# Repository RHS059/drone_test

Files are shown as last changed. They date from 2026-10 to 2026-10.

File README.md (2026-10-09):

# Six-Wheel Builder

[Open the viewer](https://rhs059.github.io/drone_test/).

Source-backed six-wheel engineering viewer with original retained drive/suspension/steering interfaces, body panels and battery/electrical components, plus licensed UR20/Robotiq mechanisms and a separate live MuJoCo gripper experiment.

See [the current assembly record](docs/RECONSTRUCTION.md) and [original source downloads](docs/assets/connected-sources/index.html). Independent front/rear steering, wheel spin and optional unloaded suspension study are executable. Purchased profiles, wheel-seat approval, load/fatigue ratings, complete wiring, UR controller mounting and vehicle operation remain open. The old workshop cradle is disabled because it intersects this revision.

The supported main isolator-to-BMS cable pair has its own [source and limits](docs/assets/main-pair-E05/index.html). Full electrical continuity remains unfinished.

Run `node test-main-pair.mjs`, `node test-real-gltf-body.mjs`, `node test-connected-mechanics.mjs`, `node test-current-rover.mjs`, `node test-composed-body.mjs`, `node test-electrical-scene.mjs`, `node test-rigid-matrix.mjs`, `node test-controls-ready.mjs`, `node test-costs.mjs`, `node test-cad.mjs`, and `node docs/contact/scripts/validate.mjs`. Historical C03 tests and assets are retained as history, not current assembly qualification.

The exact public files are listed in the release manifest. Restricted manufacturer CAD, private credentials and review-only geometry are excluded. Source-specific licenses and original modeling assumptions remain with each package.

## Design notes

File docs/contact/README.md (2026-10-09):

# Standalone reconstructed gripper contact laboratory

This is a **new reconstruction**, not recovered historical test parameters or a claim that the original package survived. It does not validate a complete six-wheel robot, manipulator, compliant object, hardware, or a contact-calibrated digital twin.

## Reproduce

Serve this folder with an ordinary static HTTP server and open `index.html`. All browser imports are relative and vendored. It runs actual official MuJoCo WebAssembly locally in the browser; recorded CSV/JSON is not used to animate it.

Native: install official `mujoco==3.15.0` into your environment, then run `python scripts/run_native.py`. In the reconstruction workspace the invocation was `PYTHONPATH=/tmp/ugv-mjpy python scripts/run_native.py`.

WASM and parity: `node scripts/run_wasm.mjs && node scripts/validate.mjs`. Both runtimes report 3.15.0. `scripts/browser_qa.py` uses Playwright and Chromium against localhost port8788. `scripts/build_scenarios.py` regenerates the original coupon STEP/STL (requires CadQuery) and experiment XML. `scripts/fetch_sources.py` captures official pinned Menagerie files; see `sources.json` for immutable URLs and SHA256 checksums.

## Model and exact units

- Google DeepMind MuJoCo Menagerie Robotiq2F85, commit `0059d4335f8156206f63a35662313385f7ad6d74`. Source XML and eight STL geometry files are retained unchanged, together with BSD-2-Clause license, README and changelog.
- Menagerie meshes are millimetres; the upstream mesh scale remains `0.001 0.001 0.001`. Joint positions, inertias, masses, tendon, two closed four-bar connect constraints and driver equality remain sourced from that model.
- Coupon is an original analytic rectangular solid,40×40×30mm, centered at CAD origin. STEP and STL are in **millimetres**. It is freshly generated, not a recovered historical binary. MJCF collision is the exact equivalent box with half sizes `0.02 0.02 0.015` **metres**; no mesh simplification changes its shape.
- Simulation SI units: metres, kilograms, seconds, Newtons. Mass is independently assigned, not inferred from the coupon CAD material. Nominal and low-friction0.15kg; heavy2kg. These masses correspond to artificial test loads rather than a claimed material density.
- Upstream gripper pad collision proxies remain the original boxes. Link mesh collisions use MuJoCo convex collision geometry, as standard in Menagerie. This is not a soft silicone or deformable-contact model.

## Declared scenario

`scenario.json` is the authoritative parameter declaration. Gravity9.81m/s², timestep1ms, implicitfast integration,100 solver iterations, tolerance1e-10, elliptic friction cone. Duration5.5s;550samples at10ms intervals per case. Gripper mounted downward atz0.3m; coupon center initiallyz0.1512m. Source position actuator command ramps0→200 at0.2–1.2s, force limits remain upstream±5.

The only coupon weld is explicitly `initial_world_fixture`, coupon-to-world, active until1.5s. It is disabled permanently before transport. **There is no object-to-gripper weld or kinematic object following.** The gripper base follows a prescribed100mm horizontal smoothstep at2–3.5s. Gripper opens at4s. Coupon position, contact, normal forces, falling and slip are solved from dynamics.

Nominal friction0.7; low-friction0.015; heavy friction0.7. Coupon geom priority2 makes these sliding coefficients effective for contacts against upstream priority1 pads. Torsional and rolling friction are0.005 and0.0001. Strict task PASS means maximum Euclidean coupon-to-prescribed-center error is **less than10mm** over1.6≤t<4s. Heavy is a changed load, not necessarily a failing negative control.

## Fresh measured results

Native / WASM strict task results agree:

- Nominal: worst transport error2.61103mm, **PASS**.
- Low friction:152.31481mm, **FAIL**, real slip/drop before opening command.
- Heavy:2.37696mm, **PASS**.

Nominal/heavy commanded release is observed: coupon remains above0.1m immediately before4s and falls below0.05m by5.5s. Low-friction already dropped and is deliberately **not** counted as successful commanded release. The software regression harness can pass while the low-friction experiment fails.

Maximum sampled native/WASM coordinate difference is1.2915µm and contact-normal-force difference0.03704N. The initial1µm numerical gate **failed**. A documented10µm gate is used for nonsmooth-contact numerical agreement (1000× tighter than the10mm task gate); the original failure is preserved in `summary.json`. This is bounded numerical agreement, never exact bitwise parity or real-world validation.

Pad force is the sum of scalar normal forces only for coupon–pad contacts. Total contact normal force additionally includes the floor; a heavy coupon's floor impact peak must not be presented as gripper force. Raw sampled position, qpos, fixture status, command and forces are retained in native/WASM JSON.

## Browser QA status

Live Node execution of the same WASM module passed. Browser launch in this executor is blocked: Chromium cannot create its process-singleton socket (Operation not permitted), including an escalated retry. Browser screenshots, visual layout, pause/reset and actual browser loading therefore remain unverified until a permitted browser environment runs `scripts/browser_qa.py`. This is recorded separately in `results/browser-qa.json`.

## Browser module API

`createEngine(readBytes?)` loads official single-threaded WASM. Default asset loader uses relative fetch. `engine.createCase('nominal'|'low-friction'|'heavy')` returns `{model,data,mj,step(),sample(),dispose(),stepCount}`. Call5500steps and sample every10steps. `summarize(samples)` calculates declared metrics. `validateParameters()` rejects invalid nonfinite/nonpositive masses and negative/nonfinite friction; the shipped UI deliberately exposes only the three fixed declared cases.

## Attribution

Menagerie Robotiq model:BSD-2-Clause, retained `assets/robotiq_2f85/LICENSE`. Official MuJoCo3.15.0 JavaScript/WASM:Apache-2.0, retained `vendor/LICENSE-MUJOCO`, package README and metadata. Three.js renderer:MIT, retained `vendor/THREE-LICENSE.txt`. Original scenario, scripts, UI and coupon are new work for this reconstruction. No private soldier assets or external CAD are involved.

Validation is read-only by default. To intentionally regenerate the summary after new native/WASM runs: `node scripts/validate.mjs --write`.

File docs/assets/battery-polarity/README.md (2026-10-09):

# BA02 polarity correction R01

This separate correction establishes the functional polarity of the four existing BA02 terminal interfaces. It changes viewer labels and semantic terminal colors only. It does not modify the frozen BA02 CAD, source generator, geometry, transforms, source node names, or original source/evidence ZIP. No vendor PDF, image, mesh, logo or manufacturer geometry is included.

## Result

In the installed BA02 frame, positive is **Y +275.25 mm** and negative is **Y −275.25 mm** on both batteries. The original node names assigned these polarities backwards.

| Frozen source alias, retained unchanged | Verified functional polarity | Terminal-axis top in CAD C, mm | Viewer color |
|---|---|---|---|
| `BA02_pack_1_negative_M8_interface` | Positive (+) | (−1029.05, +275.25, 169.6) | Red `#e53935` |
| `BA02_pack_1_positive_M8_interface` | Negative (−) | (−1029.05, −275.25, 169.6) | Dark `#20252b` |
| `BA02_pack_2_negative_M8_interface` | Positive (+) | (−679.05, +275.25, 169.6) | Red `#e53935` |
| `BA02_pack_2_positive_M8_interface` | Negative (−) | (−679.05, −275.25, 169.6) | Dark `#20252b` |

These colors are a deliberate viewer convention, not source evidence about physical terminal coating or insulation color. The frozen source used a shared bronze terminal material for both polarities and the top fittings.

## Exact source and orientation proof

The official Victron Energy BAT548110620 drawing is [LiFePO4 Battery 51.2 V / 100 Ah NG, Dimension Drawing](https://www.victronenergy.com/upload/documents/LiFePO4-Battery-51.2V100Ah-NG.pdf), page 1, top plan view. Its rendered polarity marks were visually inspected on 2026-10-09: positive on drawing-left and negative on drawing-right.

Exact inspected PDF SHA-256:

`d153636d0bb1cb84ea4c3c339746618c97fd02859398404febbc8a92a2a27d4b`

1. The drawing's overall width is 647.6 mm. Its asymmetric top fitting is 376.3 mm from the left edge, hence 376.3 − 647.6 / 2 = **+52.5 mm toward drawing-right**.
2. The frozen BA02 fitting center is **Y −52.5 mm** on both packs. Therefore drawing-right maps to **CAD −Y**. The asymmetric fitting, not terminal names or existing wires, resolves the orientation.
3. Positive is on drawing-left, so it maps to **Y +275.25 mm**. Negative is on drawing-right, so it maps to **Y −275.25 mm**. The absolute axis offset is the frozen symmetric terminal pitch, 550.5 / 2 = 275.25 mm.
4. The terminal depth-edge offset establishes X = pack center − (161.5 / 2 − 26.7) = pack center −54.05 mm. Pack centers are X −975 and −625 mm.
5. Z 169.6 mm is the preserved BA02 terminal-reservation top. It is not a newly qualified hardware height. The existing source-height discrepancy remains unresolved.

The drawing's rounded 48.5 mm end offset differs by 0.05 mm from its symmetric pitch-derived location. This metadata-only correction preserves the frozen axis placement. The source/mesh regression uses a 0.01 mm tolerance only for tessellated-circle extrema and float32 mesh positions; exact manifest and contract dimensions use 1e-7 mm tolerance.

The frozen generator's note that installed polarity is an orientation choice is superseded by this correction. Its legacy names remain trace aliases only. Do not use those words to infer electrical polarity.

## Runtime integration

Copy `apply-battery-polarity.mjs` and `battery-polarity-contract.json` together with the viewer's original runtime assets. After all named body patches have composed BA02 and the normal asset loader has assigned its labels, call:

```js
import { applyBatteryPolarity } from './apply-battery-polarity.mjs';
const polarityContract = await fetch('./battery-polarity-contract.json').then(r => {
  if (!r.ok) throw new Error('Battery polarity contract unavailable');
  return r.json();
});
const polarityResult = applyBatteryPolarity(body, polarityContract);
```

`body` is the composed source-frame Object3D, not a newly generated or moved battery. The helper is import-free and supports Three.js Object3D and Material APIs already used by the viewer. It:

- Validates the exact drawing hash, source dimensions, marked sides, asymmetric-fitting sign, all four functional mappings, labels, colors and open qualification gates.
- Resolves all four legacy aliases uniquely before staging changes. Missing or duplicate source nodes throw without modifying the scene.
- Stages all material clones and metadata before applying them. A late clone failure leaves the scene unchanged. Each cloned material must have its own color object.
- Retains each `node.name` exactly, and stores its source alias and verified functional identity under `userData.batteryPolarity`.
- Sets `userData.label` and `userData.displayLabel` on each terminal source node and every descendant mesh, so the viewer's mesh-selection label reports the functional polarity.
- Gives every corrected mesh an independent cloned material; array materials are supported. It does not recolor shared original metal, either top fitting, or unrelated hardware.
- Never writes geometry, node names, hierarchy, position/quaternion/scale, visibility, local/world matrices or update flags.

The proposed functional identity is `BA02_pack_{1,2}_{positive,negative}_M8_interface_VERIFIED_R01`. This is metadata only, not a silent runtime `node.name` rename. A circuit or endpoint graph must retain the exact source alias for geometry resolution and use the verified functional polarity/name for its electrical semantics. Existing cable paths do not establish polarity or authorize their own connections. The electrical owner must separately reconcile any affected edge labels and endpoints.

Suggested viewer download notice:

> Frozen BA02 CAD keeps its original source node names, which invert the terminal polarity wording. The viewer applies the separate BA02 polarity correction R01: positive Y +275.25 mm and negative Y −275.25 mm. Consult the correction map before using terminal names. Wiring and terminal/lug qualification remain open.

Link that notice directly to this correction package when publishing the immutable BA02 download.

## Regressions and preserved inputs

`battery-polarity-contract.json` records the source facts, derivation, source-to-functional map, labels/colors, gates and SHA-256 hashes of all 17 frozen inputs, including the BA02 generator, all frozen BA02 artifacts and original archive.

Run the independent, read-only source/mesh regression from any directory:

```sh
python verify-source-polarity.py --ba02-root /path/to/battery-alternative --source-pdf /private/path/to/official-drawing.pdf
```

The PDF argument is optional for a redistributable text-only package. When supplied, its exact bytes are hash-verified without copying it. Without it, the report explicitly says `not_supplied`; the script does not claim a fresh PDF verification. The script checks actual GLB vertices, the asymmetric fitting, four terminal positions, functional polarity, semantic colors and preservation of all frozen hashes. It does not machine-read the plus/minus artwork; that observation comes from visual inspection of the hashed source document.

Run the runtime regression in the original workspace layout:

```sh
node test-battery-polarity.mjs
```

For another workspace, point `THREE_MODULE`, `CAD_READER_MODULE`, and `BA02_GLB` to existing viewer dependencies and the frozen BA02 GLB. The reader must return Three.js Object3D meshes in unchanged source coordinates. No dependencies or vendor meshes are bundled here.

The recorded runtime result passes 14 tests against the actual frozen BA02 GLB: source/fitting derivation; measured terminal/fitting positions; all four labels/colors; preserved geometry/matrices; shared-material isolation including array materials; missing-node and duplicate-node atomic failure; late clone failure; shared-color clone rejection; reversed-source/coordinate/gate negative tests; and repeat application.

Files `source-regression-results.json` and `runtime-regression-results.json` are bounded test evidence, not certificates of a working electrical assembly.

## Qualification limits

Only polarity interpretation is source-verified. The following remain false or open:

- Terminal hardware, recess, lug, bolt and cable-contact qualification
- Full harness completion and physical electrical continuity
- Protection, BMS, fusing, isolation, controls and conductor selection
- The underlying source-height discrepancy or exact vendor hardware reconstruction
- Vehicle operational or electrical safety qualification

No cable continuity test is used as proof of polarity, no physical reconnection is performed, and no complete-wiring gate is closed by this patch.

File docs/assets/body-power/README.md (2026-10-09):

# Body/power R01: original engineering CAD

This package replaces an exposed ladder-only appearance with functional compartment geometry. It is a manufacturing-development assembly, not fabrication-released, electrically qualified, weatherproof, crash-rated or ready to operate.

## Coordinate and source contract

All original construction is parametric CadQuery B-rep in millimetres, frame C: X forward, Y left, Z up. GLB vertex positions are metres and Z-up; no root correction rotation is required. Mount origins remain the R06 frame origins. Geometry is not stretched to match photographs.

- `body_power_R01.step` / `.glb`: original sheet parts, rail straps, stiffeners, hatches, gaskets, hardware approximations and cable troughs. No purchased electronics are disguised as detailed CAD.
- `cots_reservations_R01.step` / `.glb`: six explicitly named DIMENSION_ONLY cuboids: four RELiON batteries and two UR OEM DC controllers. Load only as a separate optional translucent packaging layer.
- `build_body_power.py`: reproducible source. `python build_body_power.py` rebuilds and verifies. CadQuery 2.7 and NumPy are required.
- `verification.json`: current solid validity, actual bounds, geometric mass/CG assumptions and intersections. Frame, arms, wheels and drive masses are excluded.
- `original_cutlist.csv`: one row per original part. This is a finished-geometry list, not a released flat-pattern/nesting set.
- `sourced_bom.csv`, `SOURCES.json`: primary-source identity, dimensions, mass and limitations. No purchase or vendor approval is claimed.

## Mechanically useful features

The recessed battery well sits between the existing X −1200 and −400 crossmembers, inside the rails. Four upright 260×180×276 mm reservations rest on 4 mm isolator pads; the reserved bank weighs 62.4 kg. Its original aluminium floor/walls, low stops and top crossbar provisions are explicit solids. Terminal positions and a validated hold-down contact interface remain unknown; the bars have a 12 mm nominal clearance and must not be represented as a completed restraint design.

The rear bay has two distinct elevated controller mounting trays with actual adapter slots, free connector/air volume and removable top access. The middle bay is retained as tool/payload volume. The forward compartment uses a real planar sloping nose and removable hatch. No weapon, targeting system or weapon mounting interface is included.

The outer body has separate 3 mm panels, shaped transverse bulkheads, sloping shoulder plates, four side inspection panels, top hatch joints with gasket solids, M6 clearance holes/nutplate provisions, simplified socket-head screws, cable troughs and actual connector/vent apertures. The top remains segmented for access. Rails are attached using wrap-around strap-clamp provisions, with no undisclosed new holes in the inherited frame. Fastener threads, bolt preload, rivet-nut choice, weld details, bend allowance, insulation and bonding still need engineering release.

The broad upper-hull span is a design choice suggested by non-dimensional reference-image cues. Its underside respects the current provisional suspension reservation; that does not establish swept-envelope clearance. The lower body has explicit cutouts for the current station-centred wishbone clamp reservation, at X −1350, 0 and +1350 mm. Do not use the superseded trailing-arm relief positions.

## Service and access

The battery hatch removes vertically; all four battery envelopes can then lift vertically with restraints removed. The controller bay is top-accessible; full connector extraction and fan service remain to be validated against acquired supplier CAD. Side inspection panels are supplemental, not battery-extraction doors. Front and middle tool hatches are separate from arm mounting plates. The arm bases at X900, Y±300, Z130 mm retain their existing bolt patterns; arm-link clearances must be checked in the actual default and motion poses.

Finger slots and ventilation openings are intentionally open geometry. The concept gaskets do not confer IP protection: sealed handles, fans/filters, drains, glands, cable penetrations and full thermal/environmental qualification are outstanding. The design must not be sold or described as a sealed battery enclosure or a certified safety system.

## Power architecture limits

The four proposed batteries provide 6.144 kWh nominal arithmetic energy, not usable energy or range. Their individual ratings do not imply system current capability. The UR source lists OEM DC input 19–72 VDC, up to 400 A inrush and 350 W control-unit heat per UR20. Two controllers require verified precharge/soft-start, fuse coordination and thermal design; nominal voltage overlap is insufficient. Standard UR control boxes require AC and are not equivalent to these provisional OEM DC reservations.

At a hypothetical 15 K air rise, removing the 700 W combined controller heat bound would require roughly 0.039 m³/s ideal airflow using assumed air density 1.2 kg/m³ and heat capacity 1005 J/(kg K). This calculation excludes pressure losses, ambient extremes, drive losses, battery heat and fan derating. It is a sizing warning, not fan selection or a cooling-performance claim. Current small vent slots alone are not qualified to deliver this flow.

Traction motors/controllers, regeneration, contactors, fuse ratings, BMS coordination, charger, emergency stop architecture, functional safety and grounding are all unresolved. No WD220 proprietary/restricted CAD is part of this package. No electrical connections are portrayed as a qualified system.

## Verification meaning

Mass is computed from CAD volume using stated nominal densities. Battery/controller masses come from manufacturer data; their CGs are placed at envelope centres as assumptions. This does not validate full-vehicle CG, tip stability, axle loads, braking or manipulator reaction loads. Frame mass and structure remain a separate package and may be redesigned. Pairwise positive-volume checks are CAD interference checks, not strength, safety or manufacturability certification.

The original bumper tubes are open-ended hollow-section geometry with separate caps. They are unqualified guards, not towing/recovery points or impact-rated bumpers. No recovery rating is invented.

## Traction candidate and optional second bay

The WD220 drawing lists47A within the motor block, without explicitly defining DC-bus input current. Six such ratings sum282A arithmetically; that is not verified battery demand. Inverter current/efficiency data are needed. A separate power check is possible: if six drives simultaneously deliver2.2kW mechanical output each,13.2kW/51.2V requires257.8A even at ideal100% efficiency, before arms/auxiliaries. Actual input would be higher. This exceeds the four batteries'180A summed individual recommended discharge, but does not by itself exceed the400A sum of individual maxima; neither sum is a qualified pack rating. The motor duty is S2 for60minutes, not continuous. Drive price and exact mass are unquoted/unknown. No motor/controller/battery compatibility is claimed. Controller heat is used for cooling sizing only and is not added again as independent electrical input power.

A separately recessed optional four-unit bay is geometrically possible within the R06 opening between crossmembers X−400 and+750mm, provisionally at X[−300,+350],Y±360,Z[−80,+337]mm. It is not modeled or included in mass/capacity. The present tool-bay interior is234mm high and cannot hold276mm batteries above its unmodified floor. This variant requires a new lowered well, changed floor, qualified retention and loss of that tool/payload volume; electrical limits do not disappear by adding units. See reservation_checks.json.

## Portable / Colab execution

The package includes the original reference_frame_R06.step solely for body/frame interference checks. Run the included requirements installation in an authorized Python/Colab environment, then build_body_power.py. Main STEP/GLB generation does not depend on private assets or network downloads. The optional arm-screen scripts require the separately licensed original robot asset folder; set its path in check_arm_clearance.py before use. This package was executed in the current engineering environment; it does not claim execution in Colab.

## C02 suspension packaging update

Current provisional wheel centres are Y±0.94m and Z−0.25m, superseding Y±0.86m. The lower corner relief is480mm wide belowZ132mm. Local160mm-wide coilover service notches extend toZ215mm. C02 shock envelopes are Xstation±60mm, |Y|520–800mm and Z−430..200mm; no actual spring has been selected. The source-dimension tyre concept is876.3mm OD and317.5mm provisional section. The analytic parallel-link, locked-steering ±12° check gives about94mm minimum lateral body-to-tyre envelope separation; this is not actual tyre/rim fit, loaded clearance or certified travel. See tire_envelope_screen_C02.json and reservation_checks.json.

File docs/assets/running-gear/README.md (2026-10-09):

# Archived source reference

These BSD-licensed Clearpath Warthog models were acquired for comparison. They are not loaded by the current six-wheel vehicle scene and are not the selected wheel or drivetrain. The selected source-backed wheel model is in ../wheels/. Original four-wheel Warthog ratings do not qualify this six-wheel design.

# Genuine running-gear source assets

Retrieved 2026-10-09 from the official Clearpath Warthog ROS description distribution:
https://github.com/warthog-cpr/warthog/tree/kinetic-devel/warthog_description

## What this contains

- Original OEM-distributed STL simulation meshes: wheel, two-wheel rocker enclosure, fenders, differential link and suspension link.
- GLB conversions in metres, Z up. Wheel, rocker and fender GLBs rotate the source by Z+90 degrees, preserving every triangle and applying NO scale. Remaining links preserve source coordinates. See interface-contract.json.
- Source Xacro graph, package BSD declaration and repository BSD-3-Clause LICENSE.
- Per-file upstream Git blob IDs and URLs in source-manifest.json, actual downloaded SHA256 hashes, triangle counts and bounds in geometry-report.json.

These are CAD-derived source **meshes**, not STEP/B-rep solids or toleranced manufacturing drawings. Wheel geometry is 12,680 triangles. It is not watertight after exact vertex merging; no topology repair or invented hub was introduced.

## License evidence

The root BSD-3-Clause license and robot-description package.xml BSD license are included. The mesh directory listing contains no separate license/exclusion. This is the published distribution's license evidence, not an additional legal opinion or grant of patent/trademark/manufacturing rights. Retain LICENSE in source and redistributed GLB documentation; do not imply Clearpath endorses the new assembly.

## Fit and limitations

Wheel GLB origin is the OEM axle center; axle +Y; nominal tire 610 mm; actual rotating mesh envelope radius 304.931 mm; actual width 254.300 mm. The source's 15 kg mass and radius 300 mm are simulation parameters. Hub bolt circle, pilot, axial mounting plane, rim offset, tire pressure/load curve and radial/axial load limits are NOT verified. Wheel has simplified filled low-poly center faces, but no identifiable lug holes; it does not provide an independent hub or motor assembly. A ray along its axle intersects mesh at sourceX -0.08654228 and +0.001998188 m (GLB Y after rotation), not certified mounting planes. Do not label a newly designed spindle as OEM-compatible without the supplier drawing.

Source Warthog is four-wheel, 1.52 x 1.38 x .83 m. Its whole-vehicle 280 kg base and 272 kg payload do not qualify the sedan-size six-wheel design. Its unmodified rocker holds TWO wheels at 914.734 mm wheelbase and cannot be transplanted onto the six single-wheel stations. Rocker and link GLBs are reference-only unless used in a fully redesigned and verified layout. The source labels the diff-link purely visual and does not model a constrained suspension linkage or motor internals.

## Purchasable candidates, not CAD/fit matches

The OEM manual identifies a 610 mm Argo Turf tire but does not identify an exact stock wheel part. A dealer offers a current 24x10-8 Argo XT115 tire (10002C) at USD380.74 and standard steel mounted left/right assemblies (10002C-STD-LEFT/RIGHT) at USD498.45 each, observed2026-10-09:
https://www.argoadventure.com/10002C--24x10-8--ARGO-XT115--TIRE-ONLY_p_18093.html
https://www.argoadventure.com/Standard-8-Rim-and-Tire_c_3689.html
These are procurement leads only: XT115 is not verified as the source's Argo Turf tire, and no load/bolt/mounting equivalence is established. Price excludes shipping/tax.

A separate dealer identifies Argo125-13BL 8x7 steel rim as five-lug,4.5-inch pattern, but this is NOT proof that the Warthog mesh depicts that rim:
https://adair-argo-sales.myshopify.com/products/rim-8x7-5-bolt-black

Timken32008X official CAD/product lead (not downloaded; page returned410 through web fetch):
https://cad.timken.com/item/tapered-roller-bearings-ts-tapered-single-/tapered-roller-bearings-ts-tapered-single-metric/x32008xm-y32008xm

No suitably sized license-safe motor/geared-hub CAD was acquired. Do not replace this gap with invented internals or a toy motor design.

## Rebuild

Run convert_assets.py with numpy/trimesh available. Exact source mesh arrays are retained; per-vertex visual gray is assigned only for visibility. Validate wheel rotation/contact using interface-contract.json; glTF loader must honor the documented Z-up content, because glTF conventions otherwise commonly assume Y-up.

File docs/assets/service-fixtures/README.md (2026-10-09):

# S01 original static workshop fixtures

Engineering-development CAD, not fabrication released or safe to use. These original fixtures have no safe working load, proof test, material-grade approval, weld design or stability approval. They are not lifting equipment, commercially rated stands, an autonomous mechanism or manufacturer-approved accessories.

Current corner contract: C02_R05, retaining upright R04 and wheel adapter R02. Adapter R02 changes only pilot-hole size, so fixture placement is unchanged.

## What is actually modeled

- Two independent original transverse chassis trestles at X = −1775 and +1775 mm. Each has a plate-built hollow crossbeam, two vertical hollow posts, two floor plates and two rail-bearing saddles. The frame is not drilled, cut or welded.
- Four 160 × 220 × 16 mm saddle plates bear directly under the R07 200 × 100 × 6 main rails at Y = ±460, Z = −100 mm. Each spans the complete rail width. Actual contact is the rounded rail's 76 mm-wide bottom flat; local web/bottom-wall load transfer remains unqualified.
- Four screw-adjusted side locators per saddle provide an actual mount/registration mechanism. Gravity flows through the saddle into the trestle, not through locator friction. Locator screws must never be called lifting points or relied on to prevent uplift. The side bosses have smooth bores representing unresolved threaded manufacture; threads, screw locking, tip attachment, preload and rail wall crushing need design review.
- A separate floor-supported wheel-corner cradle uses two hollow contour-shoe weldments, replaceable nominal 6 mm elastomer liners, two longitudinal rails, two transverse rails and four feet. The shoes follow the selected tire's stated 438.15 mm unloaded radius. The tire model is original C01 reference geometry; fitted width, actual tread contact and compression are unknown.
- Four removable bolted capture-post weldments and two removable bolted crossbars form an enclosing cage around the tire. The posts must be removed during cradle insertion. The cage is not a rated restraint, lifting bail, tie-down or personnel guard. No hoist hooks, drive-housing contact geometry, wheels, casters or autonomous motion are invented.

STEP is millimetres. GLB is metres, Z-up, in rover C coordinates (X forward, Y left). The cradle is at the middle left wheel; apply a proper Rz(180°) rotation for the right side, then translate X to the desired station. Do not use negative scaling. Four-point chassis saddle centers form a 3550 × 920 mm rectangle. This does not demonstrate a stable vehicle in any arm pose.

## Deliberate service scene and height

The nominal C01 tire floor is Z = −688.15 mm. S01's illustrative floor is Z = −788.15 mm, representing a 100 mm raised chassis while the C02 links remain at q = 0. The chassis saddle underside is Z = −116 mm, therefore 672.15 mm above this floor. The trestles are purpose-dimensioned original CAD for that one pose; they do not telescope or lift. Each fixture must be positioned before receiving load. Other heights require engineering a different fixture; do not add loose packing.

ESCO 10498 is not assigned to this model. Its maximum 546 mm saddle height is below even the unraised saddle underside (572.15 mm), and its manual limits accessories/adapters to manufacturer-supplied ones and prohibits adding material for height. US Jack taller candidates do not automatically solve the configuration: their one-end matched-pair usage restriction must not be reinterpreted as approval for four stands under the full vehicle. No commercial load rating transfers to S01. At either end wheel station, the nearest cradle and trestle foot edges have only 5 mm nominal lateral separation. Placement tolerance, floor unevenness and loaded deflection must be checked; this is not a released workshop aisle or installation clearance.

The CAD-only assumed mass is about 97 kg per trestle and about 90 kg for the cradle (see the latest verification JSON for exact values). They are not hand-lift or UR20 payloads. A separate reviewed handling/positioning method is required before these fixtures can be deployed; none is claimed by this geometry.

## Load paths and remaining interfaces

Chassis: main rail bottom flat → saddle plate → transverse box → two vertical boxes → floor plates → qualified floor. Locator screw loads, local rail bending/crushing, column buckling, box torsion, eccentric loading, welds, base plate bending, foot contact, anchorage and overturning are unresolved.

Corner: tire tread → liner → curved shoe top/walls/base → transverse members → longitudinal members → floor plates → floor. The drive/upright hangs inboard from the wheel through existing joints, so the full module mass and CG must be measured and a tip/stability calculation performed. The original upright is deliberately not supported on guessed OEM drive housing surfaces. A future direct upright support should contact checked original non-bearing lands; S01 does not add one.

The CAD's two contact shoes and enclosing cage do not establish adequate module retention. Liner bonding/mechanical retention, tire condition/inflation, compressibility, proof loading, blocked-movement behavior, lateral capacity and floor anchorage remain gates. Ground contact is not automatically anchorage: foot holes are original unqualified patterns and no anchors are selected.

## Bounded C02 removal and inspection sequence

This is a proposed design sequence for review, not an executable approved workshop procedure. Do not proceed past a missing precondition.

1. Establish an approved vehicle isolation/lockout plan; isolate traction and arms, control brake release, chock the still-grounded wheels and identify stored energy. C02 connectors and the coilover are not selected, so those manufacturer procedures remain open.
2. Measure the entire vehicle and removable-module masses/CGs; calculate worst-case support reactions and all intermediate stability cases. Select and qualify actual lifting points, jack/hoist, sling/fixture, headroom and lift height. S01 supplies no lifting attachment; the current frame has no qualified lifting lugs. Initial raising is blocked until this is resolved.
3. With qualified equipment carrying the load under human supervision, position the two engineered trestles and the unloaded cradle at the selected corner. Remove the cradle's four capture-post weldments and two crossbars for insertion, leaving its floor frame/shoes assembled. The 100 mm raised q = 0 pose is illustrative; actual suspension droop and insertion clearance need checking. Seat all four chassis saddles and the corner support through a reviewed load-transfer process with load measurement. Do not assume equal stand reactions or four-way load sharing.
4. Install and inspect the cradle's four post weldments (eight base fasteners) and two crossbars (four upper fasteners). Establish independently qualified anti-tip/anti-rotation restraint for the actual corner, and check full module load/CG. Do not release a corner held solely by robot arms.
5. Positively support both wishbones in their retained chassis position and control all coilover/spring energy by the selected manufacturer's procedure. Those support devices are not in S01, and the planned C02 coilover is unselected: pin release remains blocked. The chassis rail clamps and their through-tie hardware remain installed.
6. After the preceding checks are released, isolate/disconnect the exact drive/brake/sensor connectors and remove the retention devices for the two outer X-axis upright pins. Final pin retention is not designed in C02. An original Ø28 mm extraction corridor from X −260 to +260 mm was screened against the S01 cradle ONLY. A subsequent exact containment test finds the installed modeled tire on that centerline at X offsets ±220 mm. The full corridor is obstructed; a verified wheel-first or alternative-access procedure and real extraction tool are required. See pin_axis_tire_obstruction.json. Withdraw the two outer pins only while the external workholding carries the corner and both links remain positively supported. Do not remove inner pivot or rail-clamp bolts.
7. The C02 service boundary is wheel + adapter + drive + upright. Wishbones, stationary rail clamps and planned coilover remain on the chassis. Keep the detached module supported in the stationary cradle for inspection. Moving it away, lifting it or rolling it requires a separately engineered transport/lifting attachment and sequence; S01 deliberately does not animate or assert that operation.
8. Reassembly requires qualified pin/bearing retention, hardware grade/engagement/torque, connector/brake checks, witness inspection and controlled transfer back onto tires. No numeric tightening torque is invented.

This sequence is C02-specific. A future steering tie rod/actuator adds another connection and cannot inherit this removal boundary without revision. Current fixed UR20 bases cannot reach the rear wheel station (2.25 m longitudinal separation exceeds 1.75 m nominal reach); rear service is human-assisted. Reachability and payload/moment limits still need verification for every proposed arm operation at other stations. Tools, coupling, gripper and workpiece all count. Two robot payload ratings cannot simply be added.

## Files and reproduction

- `chassis_trestles_S01.step/.glb`: the two original chassis fixtures
- `corner_cradle_S01.step/.glb`: one original cradle, left-middle C02 pose
- `service_fixtures_S01.glb`: both groups together; reference vehicle not bundled
- `build_fixtures.py`, `parameters.json`: editable source and explicit parameters
- `verify_interfaces.py`, `interface_verification_S01.json`: file-level nominal geometry screens against R07 frame, original R01 body, original C01 wheels and original C02 interfaces
- Per-group verification JSON and `parts_S01.csv`: solid counts, assumed CAD-only masses, contacts and interference reports
- `service_interface_contract_S01.json`: placement, grouping and blocked operations
- `SOURCES.json`: official equipment source references, no downloaded private source files

Run `python build_fixtures.py` with CadQuery 2.7 and numpy, then `python verify_interfaces.py` alongside the declared original reference packages. The generator imports no private motor CAD. Public outputs contain only these original fixture solids, source code, numerical checks and documentation. Geometric testing must not be reported as load qualification.

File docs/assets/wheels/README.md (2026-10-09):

# Original source-backed rover wheel C01

An editable CadQuery tire/rim assembly tied to the published major dimensions of the selected BFGoodrich KM3 72204 tire and EVO Corse SE5240060141 rim. Two valid B-rep solids; source-scale GLB in metres with explicit Z-up and +Y axle convention. A useful dimensional fit candidate with honest detail assumptions, not OEM CAD or production approval.

## Deliverables

- `build_wheel.py`: native parametric construction and export source
- `parameters.json`: dimensions, including clearly named assumptions
- `wheel_C01.step`: named tire/rim assembly, millimetres
- `tire_C01.step`, `rim_C01.step`: individual millimetre solids
- `wheel_C01.glb`: separate tire and rim nodes, metres; Z up, axle +Y
- `interface_contract.json`: mounting plane, bolt coordinates, axes and fit gaps
- `verification.json`: measured bounds, solid validation, overlap and interface tests
- `SOURCES.json`: exact public source URLs and provenance
- `ASSUMPTIONS.md`: source facts versus original detail and unresolved fit
- `SHA256SUMS`: deliverable hashes

Run with Python, CadQuery 2.7 and numpy: `python build_wheel.py`. No internet, supplier file, extra geometry library, or protected mesh is required to rebuild. The output is deterministic geometry; STEP header timestamps can differ between builds.

## Important fit facts

Measured tire OD used is 876.3 mm, not nominal 889 mm. The retained 317.5 mm tire section width was measured on a 254 mm rim and remains unverified on the selected 215.9 mm rim. Both outside dimensions remain provisional in this fit model. Rim mounting plane is +18 mm outboard of wheel center. Five assumed 18 mm lug clearance holes lie on the published 165.1 mm PCD, clocked 36 degrees from +X toward +Z. The bore is nominally 114.1 mm. A separate adapter is required for the WD220's different 140 mm PCD / 94 mm pilot.

The original perforated wheel disc and generic tread are deliberately not marketed as the appearance of either manufacturer's product. A supplier STEP request or measurement program is needed before true OEM detailed CAD accuracy is possible. Ratings of the selected catalog parts do not transfer to this original geometry or the vehicle.

## License / provenance

The authored Python source, explanatory text, JSON, STEP and mesh geometry in this directory are original work prepared for this project. They may be reused and modified for the user's rover project. No additional permission or endorsement from BFGoodrich, Michelin, EVO Corse or their distributors is represented. Names and part numbers identify dimensional references only; applicable manufacturer names and marks belong to their owners. No third-party geometry or logos are distributed. Public dimensional facts are cited in `SOURCES.json`; the manufacturers' source documents remain subject to their own terms and are not relicensed here.

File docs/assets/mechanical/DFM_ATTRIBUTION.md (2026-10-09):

DFM checker and known-answer tests authored by Claude on branch claude/ugv-cad-realism-zbrycm, commit9d4eeeb3c8902a0cc1363345cbdfa0eb7a35abde. Source retained unchanged. Reports rerun on current frame R07 and adapter R04 in scratch workspace. Geometric screening does not establish fabrication readiness or strength.

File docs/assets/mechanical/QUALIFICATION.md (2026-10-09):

# Six-Wheel Builder original CAD: new frame R06 / adapter R03

This package contains newly constructed parametric B-rep geometry. Prior R04 frame and adapter source bytes were unavailable. R06 additionally corrects the initial R05 mounting-hole phase from30° to0° relative the manufacturer drawing +X. No historical test result, old mass, or claim of byte-for-byte recovery carries forward. The STEP and GLB files represent the same newly modeled original parts. No proprietary robot, gripper, or Robotiq coupling CAD is included.

## Status

**ENGINEERING DEVELOPMENT; NOT FABRICATION RELEASED.** These are editable solid CAD parts, not illustrative blocks. Nevertheless, manufacturing, mounting, and safety-critical structural details below remain unresolved. Passing geometric checks is not evidence of structural capacity or safe operation.

## Frame R06

- Vehicle coordinates: X forward, Y left, Z up. Overall 4000 × 1020 × 230 mm, bounds X −2000..2000, Y −510..510, Z −100..130.
- 18 separate solids: 2 longitudinal hollow RHS rails; 8 transverse hollow RHS members; 2 drilled arm plates; 6 triangular gussets.
- Main and transverse members: nominal RHS 200 high × 100 wide × 10 wall. Outside corner radius 20 and inside radius 10 mm are explicit NEW design assumptions, requiring stock-supplier confirmation.
- Transverse blanks extend to Y ±430 before being coped to the complete rounded outer envelopes of the main rails. Material does not intrude into the rail cavities. This provides coincident mating surfaces in nominal CAD with no deliberate weld root gap. A fabricator must specify edge prep and actual weld root gaps.
- Crossmember centers X = −1950, −1200, −400, 750, 1050, 1300, 1650, 1950 mm. This layout is NEW; it is not asserted to match old R04.
- Arm decks: 400 × 400 × 30 mm at (900, ±300), top Z130. Six Ø8.5 through pilot holes per plate on Ø210 PCD, phase0° from the drawing +X axis. These are M10×1.5 tap-drill pilots, not finished threads and not the robot base's Ø10.5 clearance holes.
- Main rail/deck/crossmember placement is a nominal weldment contact design. Weld beads, consumables, fasteners, coatings, machining allowances, cables, modules and wheel assemblies are excluded from reported CAD mass.
- Steel density 7850 kg/m³ is assumed. Steel grade, allowable stress, toughness, corrosion strategy and weldability are NOT selected. Mass/inertia are recomputed from R06 solid volume; the old 559.4416875 kg value is not used.

## Arm mounting verification

UR20 base footprint Ø245 mm; six M10 mount fasteners on Ø210 PCD; robot base holes Ø10.5. Required mounting-plane flatness 0.05 mm. The 5±1 mm drawing dimension is locating-pin protrusion, NOT mounting-plate thickness. Manufacturer locating-pin centers in the drawing are (−95,−10) and (+95,−10) mm, spacing190 mm. The drawing 30° arc is measured from +Y, corresponding to M10 phase0° from +X. Drawing page axes are not automatically robot software base axes; the visual registration remains a separate check. Pin seats are not fabricated by this model. Complete finished M10 thread engagement, bolts, dowel fits/retention, post-weld stress relief and machining sequence require engineering review.

Manufacturer references (retrieved 2026-10-09):
- https://www.universal-robots.com/manuals/EN/PDF/SW5_24/user-manual-UR20-PDF_online/718-818-00_UR20_User_Manual_en_Global.pdf , assembly and mounting drawing.
- https://www.universal-robots.com/media/1824603/ur20_data_sheet.pdf , one-page technical specification. Native tool flange ISO9409-1-80-6-M8; Ø50 H7 female recess, Ø100 h8 outer flange, Ø80 pitch circle, Ø8 H7 index, 6.20 recess depth. Drawing orientation must be reconciled to software tool0.

## Original adapter R03

A NEW steel adapter concept: Ø100 body, seating faces Z0 and Z23.5, nominal Ø50 UR-facing pilot Z−2.5..0, total envelope26 mm. The pilot is on the robot side, not the coupling side. Male pilot manufacturing fit is deliberately NOT inferred from the female H7 callout. Nominal geometry must not be treated as a toleranced fit.

Six proposed Ø8.5 M8 clearance bores at Ø80 PCD, angles0,60,...300°. Proposed Ø14 counterbores depth12 from the coupling side leave11.5 mm nominal underhead material. These clearances/counterbores are original design choices, not UR specifications. Screw head, length, engagement and assembly access remain unapproved. Install UR mounting screws before the coupling; coupling Ø75 envelope covers part of the access region. A conservative nominal Ø13×8 mm M8 head envelope clears the adapter and skirt, but does not approve a fastener or installation torque.

R03 corrects an interference identified during fresh source review: the coupling has an outer annular skirt, R31.5..37.5, projecting3 mm below its central robot-contact plane. The adapter therefore has a NEW nonlocating annular relief R31..38, depth3.5 from Z23.5 (floorZ20). The skirt bottom sitsZ20.5, giving0.5 mm nominal radial/axial clearance. These are custom clearance choices, not manufacturer fits. The 12 mm-deep M8 counterbores put nominal8 mm heads atZ19.5, 1 mm below skirt bottom. R02's9 mm counterbores and unrelieved flat face were superseded because they clashed. R02 is not a released deliverable.

Four Ø5 blind tap-drill pilots, depth12, at Ø50 PCD and45,135,225,315°, intended M6×1. Threads, drill tip geometry, lead-in/chamfers and effective engagement are not modeled/released. Index pin seats are deferred. Official coupling STEP confirms nominal Ø6 index location (0,+25), but cannot establish a manufacturing fit or sufficient blind depth by itself. UR index at (0,+40) must also be reconciled with the retained tool0→adapter Rz(pi) convention.

The mandatory GRP-CPL-062 is a separate purchased electronics-containing Robotiq coupling. It cannot be replaced by this adapter. Its official overall axial envelope is16.9 mm. The +11 mm coupling→gripper transform is verified in the licensed Robotiq 2F85 coupling URDF; it is a reference-frame convention, NOT physical coupling thickness. Its Ø71 F8 /2.9 deep recess faces the gripper; it is NOT an adapter-side locating pilot.

Sources:
- https://blog.robotiq.com/hubfs/support-files/2F-85_2F-140_General_PDF_20210623.pdf , page68 Fig5-6: coupling Ø75 outside,16.9 total,4×Ø6.4 clearance on Ø50 PCD, Ø11.4 counterbores depth7.5.
- https://assets.robotiq.com/website-assets/support_documents/document/GRP-CPL-062_20190819.STEP , inspected only to confirm nominal index position; proprietary file NOT redistributed.
- https://assets.robotiq.com/website-assets/support_documents/document/online/2F-85_2F-140_Instruction_Manual_Gen_HTML_20190524.zip/2F-85_2F-140_Instruction_Manual_Gen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 , mandatory coupling electronics and ISO50-4-M6 interface.

## Required release gates

1. Independent design review: material/stock radii, dimensions/tolerances, bolt/index orientation, fits and thread engagement; purchasing traceability.
2. Structural calculations/FEA and test covering arm manufacturer reaction envelope, emergency stops, dynamic amplification, torsional loads, obstacle/impact loads, wheel/suspension loads, asymmetric dual-arm poses, fatigue and local deck/rail-wall behavior. No such checks passed in this reconstruction.
3. Weld design, access and procedure qualification; distortion/stress relief and post-weld machining to arm-plane flatness0.05 mm. Nominal coincident faces are not a weld procedure.
4. Vehicle stability/tip-over, braking, payload and human-safety risk assessment; electrical, control and e-stop integration.
5. Full actual-purchased-part interference and assembly-tool access checks over moving arm/gripper/wheel ranges. Pairwise frame checks do not cover vendor parts, fasteners, wires or swept volumes.
6. Adapter proof/loading review, approved fits, dowel seats, drill-tip/chamfer details, screw selection and tool payload/inertia settings. Full vendor part and tool0 reference-frame reconciliation.

## Reproduction

Python3 with CadQuery2.7/OCP and numpy: run `python generate_cad.py`. STEP uses mm. GLB vertices explicitly use metres and Z-up (no implicit axis rotation); viewers must apply their own declared axis mapping. Named nodes correspond to CAD solids. Verification JSON reports fresh volume, mass, center of mass, central inertia matrix and pairwise contacts/intersections. Inertia units are kg·m² about assembly/part center of mass in the stated axes. Geometric tests use ideal nominal surfaces; they do not verify manufacturing tolerances or strength.

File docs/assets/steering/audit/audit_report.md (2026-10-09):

# Independent C03 geometry / forward-kinematics audit

Result: PASS for the frozen original source and the specified pivot-compensated transform scheme. No source FK or proposed transform defect found. This does not verify that a particular viewer implementation actually applies those transforms.

## Evidence

- 5,608 poses: 36 boundary-grid cases (all four corners, q = −12/0/+12 degrees, rack = −75/0/+75 mm); 4,096 seeded bounded random poses; 964 zero-rack suspension cases; 512 mirror cases.
- Steering checked by independent contract-coordinate reconstruction and bracketed Brent root-finding of the Euclidean tie-length residual across a complete turn. The source analytic formula is not reproduced. Select the closure branch nearest neutral.
- Maximum source/reference steering disagreement: 6.72e−15 rad. Maximum tie closure error: 1.67e−15 m. Zero-rack bump steer: at most 8.89e−16 rad.
- Fore/aft coordinates reflect in X with opposite steering. Left/right coordinates reflect in Y when rack translation also reverses. Exact agreement in checked reflection cases. Actuator Y layout is intentionally asymmetric and shared by both corners, so it is excluded from the L/R position-reflection assertion.
- Wheel center = kingpin + 0.128 m × wheel axis, with maximum 1.25e−16 m error. Upper/lower arm-joint spacing remains vertical within 1.25e−16 m. Wheel and tie-pin axes remain unit length.
- Maximum sampled steering magnitude: 21.4670183183 degrees at q = −12 degrees and rack = −75 mm for front-left (mirrored equivalents also exist). Nearest competing root has an absolute-angle-selection margin of at least 0.29507 rad in checked samples.
- All 45 source guard checks pass: finite numeric inputs, nonnumeric rejection, exact limits, out-of-domain rejection, documented 1e−10 numerical boundary allowance, valid side/fore signs, and defaults.
- GLB: 76 unique named root nodes; exact 1:1 manifest mapping; no node transforms; metres, Vehicle C Z-up; vertices already baked in world coordinates.
- GLB integrated-triangle volume properties agree with CAD manifest centroids to 4.70e−6 m and volumes to 0.04475%. These are tessellation comparisons, not mechanical tolerances.
- 216 transformed GLB wheel-adapter, tie-pin and tie-tube/insert axis checks pass. Maximum geometric-axis error is 4.37e−5 degrees; centroid-to-expected-axis distance is at most 7.51e−8 m. Axis extraction uses integrated tetrahedral volume covariance to avoid bias from uneven vertex sampling.

## Required integration transforms

For a baked world-coordinate vertex x, do not add native station/side transforms again.

- Upper/lower arm: P + Rx(side × q) × (x − P), using its own fixed pivot P.
- Upright/outer pins/wheel adapter: suspensionDelta + K0 + Rz(steerRad) × (x − K0).
- Tie tube/inserts: currentInner + Ralign(nominalOuter − nominalInner, currentOuter − currentInner) × (x − nominalInner).
- Rack and inner tie pins: x + [0, rack, 0]. Fixed rack groups do not move.
- Upper/lower retainers follow their arms, not steering yaw.
- Wheel spin is applied about the resulting current wheel axle after steering/suspension. The adapter/wheel is not scaled.
- Front/rear receive the same signed global-Y rack input to obtain opposite rear steering. Do not negate the rear rack a second time.
- Side already appears in armWorldRx and in returned world axes. Do not multiply returned steerRad or axes by side/fore again.
- Middle C02 corners remain fixed-steer; they are absent from the C03 GLB.

## Files and reproduction

- boundary_fixtures_C03_R01.json: 36 independent boundary poses with all expected FK fields and closure diagnostics.
- random_fixtures_C03_R01.json: 4,096 independent seeded bounded poses.
- independent_fixtures_C03_R01.json: combined 4,132-fixture set.
- audit_summary.json: numeric comparisons, source SHA-256 fingerprints and 45 guard results.
- glb_alignment_audit.json: all 76 node/bounds/mass comparisons and 216 transformed axis checks.
- audit_c03.py and run_source.mjs: reproducible independent FK and source-runtime comparison.
- audit_glb.py: reproducible direct GLB geometry and transform comparison.

Run python audit_c03.py, then python audit_glb.py. Both are read-only against the frozen C03 source and write only in this audit directory. Python dependencies: NumPy and SciPy. The source solver is executed by Node.js without editing or copying its formula.

## Scope limits

This is geometric/FK verification only. It is not continuous collision clearance, physical qualification, motor/load/actuator sizing, dynamics, strength, fatigue, fabrication, or service approval. Private OEM source is excluded. It does not replace application-level runtime tests, tests of wheel-spin behavior, or checks of separately loaded wheel/C02/frame/body models.

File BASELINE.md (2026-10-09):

# Six-Wheel Builder — baseline 01

Static Three.js engineering workbench for a conceptual six-wheel UGV. Serve `docs/` with GitHub Pages from the `main` branch. Relative imports/assets support the `/drone_test/` project path. HTTPS is required for WebGPU. No authentication service, account data or backend is included.

Original dimensioned procedural envelopes, not production CAD. Two planning variants, travel-only quasi-static mobility calculations, source-backed reference components and clearly marked unquoted cost allowances. Assembly animation is a kinematic plan, not proof of autonomous assembly or structural safety.

## Verification
`node test-model.mjs` checks ten independently generated scenario fixtures plus parameter sensitivities. CI checks JavaScript syntax and these calculations. Actual browser rendering and hardware WebGPU activation are separate checks. WebGL2 fallback and renderer failure are displayed explicitly.

## Pages
Repository Settings → Pages → Deploy from a branch → `main` → `/docs`. The existing README/history are preserved. A root index redirects to the viewer when Pages serves /(root); /docs serves the viewer directly.

## Attribution
Three.js 0.186.1 is vendored unchanged under its MIT license in `docs/vendor/THREE-LICENSE.txt`. OrbitControls is from the same release. Vehicle geometry and application code are original. Manufacturer data/source references are recorded in `docs/mobility.json`, `docs/assembly.json`, `docs/costs.json` and the evidence panel. Manufacturer CAD has not been copied or redistributed.

## Known gates
Continuous motor/inverter and brake selection; bus/thermal duty; steering/suspension clearance; real support geometry; structural joints/fatigue; disabled-target repair; fail-safe lifting; independently deployable field gantry; printer bootstrap/acceptance; measured intervention and throughput data. Passing analytical margins is not engineering certification.

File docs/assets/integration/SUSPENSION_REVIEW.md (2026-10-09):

# C04 suspension review (Claude)

Numbers from `node docs/assets/integration/suspension_review.mjs`, which runs the viewer's own `kinematics_C04_R03.mjs`.

## How it works
- Six double-wishbone corners on clamps around the frame rails. Equal, parallel upper/lower links (0.302 m), so the
  upright translates without camber change. Declared range ±12° arm rotation = −51 / +58 mm wheel travel (109 mm total).
- Front and rear pairs steer: vertical kingpin, tie rods to a rack carriage driven by a Thomson Electrak HD candidate,
  max 20° at ±75 mm rack. Middle pair is fixed (skid/Ackermann compromise not analysed).
- Spring/damper: 2.0-in class shock with Eibach 1800.300.0200S (200 lb/in = 35 N/mm, 457 mm free, 161 mm block).
  To clear the hub drive, the shock is moved 550 mm forward (steered corners) / 350 mm (middle) of the arm station;
  the lower arm and clamp are lengthened to reach it. Motion ratio 0.517 → wheel rate 9.4 N/mm.

## Findings (largest first)
1. **Spring only suits a 1.6–2.0 t vehicle.** At 1.6 t the spring sits at 361 mm (inside the 300–370 mm screened
   range); at 2.0 t 325 mm; at the 2.92 t workshop stress case 242 mm (outside the range); at 3.94 t 151 mm, below the
   161 mm block height = coil bind. Close the mass ledger, then size rate/preload (or dual-rate) to it.
2. **Ride height is very mass-sensitive.** 9.4 N/mm wheel rate means each extra 100 kg of vehicle mass drops each corner
   ~17 mm, against only 109 mm total travel. Payload, arms and batteries will move ride height a lot.
3. **Spring load is applied on a 380 mm cantilever.** The lower eye sits at X 1.90 m, 380 mm beyond the front arm bushing
   (X 1.52). At 3.4–7.5 kN spring force that is 1.3–2.9 kN·m bending in the arm extension and roughly 2× spring force
   prying the front bushing. Heavy and fatigue-prone; shocks normally load the arm between the bushing line and the
   ball joint.
4. **High scrub.** Links are inclined ~30° at ride, so the wheel moves 0.57 mm sideways per mm of bump
   (−37 / +26 mm track change per side). Tyre scrub, jacking and a high roll centre. Aim for ≤ 0.1–0.2 near ride
   (links near horizontal at ride, or tuned unequal lengths).
5. **186 mm kingpin-to-wheel offset with a vertical kingpin.** Large scrub radius → high static steering torque and
   kickback through the rack on a ~200–400 kg corner. Add kingpin inclination and/or reduce offset; size the actuator
   force from the resulting steering torque.
6. OK: tyre-to-spring clearance ≥ 87 mm across full travel × steer; no bump stops are modelled yet (travel limits are
   software only).

## Corner connection check (live viewer scene, front-left)
`corner_contact_dump.js` samples surface points (1.5 mm spacing) from the running viewer; `corner_contact_gaps.py`
measures every declared joint. All 28 pass (≤ 1.6 mm, rod-end ball running clearance):
tyre → rim → hub-motor output flange (Ø94 pilot + 5×M16 studs, 5 nuts) → motor internal bearing → motor body → 8×M10 →
knuckle → AIN16 ball joints → arms → paired GE20ES pivot bearings → clamp → frame rail. Steering: knuckle → tie pin →
rod ends → tie tube → inner pin → rack carriage → guide → crossbeam → clamp; Electrak pin → carriage. Shock pins → eyes, clamp, lower arm.

## Drive, wheel removal and brakes
- **Drive:** each wheel is bolted straight to a WD220 hub gear-motor (48 V, 2.2 kW S2-60 min, 40.61:1, 74 rpm,
  1000 N·m max) → top speed 3.2 m/s (11.6 km/h). Mechanically complete; motor pigtails/terminals and controllers
  are not yet located or wired (electrical contract lists them as unverified).
- **Steering:** front and rear pairs steer ±20° via Electrak HD racks; middle pair fixed. With front/rear steering
  opposite, the turn centre lies on the middle axle line, so the middle wheels can roll without scrub (Ackermann not yet checked).
- **Wheel removal:** 5 nuts sit ~190 mm deep inside the rim dish (needs a long-extension socket), then the wheel slides
  30 mm outboard off the studs; nothing outboard obstructs it. But the vehicle has no jacking points modelled, the
  workshop-support placement is disabled for C04, and the wheel+tyre (~50–60 kg est.; rim 19.5 kg, tyre mass unknown)
  is beyond a UR20's 20 kg payload — the robot cannot change its own wheel without a hoist/lift aid.
- **Brakes:** none apart from each motor's internal 12 N·m electromagnetic parking brake (≈ 487 N·m at the wheel through
  the gearbox, lossless). Six together hold 2924 N·m: OK for 1.6–2.0 t on 12° with 1.5× reserve, only marginal on 20°,
  and FAIL for 2.92 t on 20°. There is no service brake, the brake's dynamic (stopping) rating is unknown, and it acts
  through the gearbox, so a gear/shaft failure leaves the wheel free.

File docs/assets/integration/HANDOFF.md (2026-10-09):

# Integration handoff — make the Six-Wheel Builder physically connected

Owner of this spec and the checks: Claude. Builder: Aella and her lanes. Each task has a pass/fail test you run yourself;
a task is done only when its test passes on the committed files. Keep all existing rules (no vendor CAD redistribution,
no qualification claims).

## Tools you run (all in this repo)
| Check | Command (repo root) | Pass |
|---|---|---|
| Connectivity | `python docs/assets/mechanical/assembly_check.py --corner` (fast) / no flag (full vehicle) | `0 floating, 0 interferences` |
| Coilover sweep | `python docs/assets/integration/coilover_C02.py` | every sweep row `clashes_mm3: []` |
| Buildability | `python docs/assets/mechanical/dfm_check.py <part>.step` | `PASS` |
| Known-answer | `python docs/assets/mechanical/test_dfm.py` | `PASS` |

Add every new part to `assembly_check.build()` (with its rover.js transform) so connectivity covers it.

## Current state (Claude, this branch)
- `integration/drive_envelope_WD220.*` — public-dimension hub-drive solid. Stator seats on upright face Y797, rotor on adapter face Y928, inside drive-reservation bounds, 0 clashes. **Closes wheel → frame.** Middle-left corner: 58/58 parts connected.
- `integration/coilover_C02.*` — coilover envelope + spring sizing. Motion ratio 0.516 (spring/wheel), stroke 56.5 mm for ±12° (109 mm wheel travel).
  Spring rate at 1.4 Hz ride: 37 / 51 / 71 N/mm for 1300 / 1600 / 2000 kg vehicle.
- **Blocking finding:** the contract coilover line (fixed eye Y560 Z170 → lower eye Y720 Z-367.5) passes **through the hub drive** (≈620 000 mm³ at ride) and clips the stationary clamp (13–990 mm³, worse in bump).

## Task A — relocate the coilover (corner C02 and the steered C03 corners)
Problem above. Requirements:
1. No clash with drive envelope, upright, pins, arms, clamp, wheel, body over the full ±12° sweep (and with steering ±max on C03).
2. Options, pick one and justify: (a) shock ahead of or behind the drive — offset in X by ≥ 140 mm (drive flange half-width 124 + 16 clearance), lower eye on the corresponding lower-arm leg; (b) twin shocks at X ±150 mm; (c) lower eye on the upper arm with a rocker. (a) is simplest.
3. Keep motion ratio 0.45–0.65; recompute with `coilover_C02.py` (update eye points via the contract) and keep the spring-rate table.
4. Select a real 2.0–2.5 in coilover by catalogue: eye-to-eye at ride within its range, stroke ≥ needed + 10 mm, spring rate from the table for the current mass ledger. Record part number, eye width/bushing, source link. No OEM CAD redistribution — envelope only.
5. Pass: coilover sweep has no clashes; connectivity shows the coilover connected (upper eye touches clamp bracket, lower eye touches arm bracket — add real clevis brackets, M12 eye bolts per STANDARD).

## Task B — 48 V power distribution and harness
Requirements (house standard: 48 V LiFePO4 bus, fuse every branch):
1. Batteries: the four RELiON reservations in parallel → two copper busbars (+/−) in the battery well. Model busbars (e.g. 40×6 mm Cu), battery lugs/terminals at the published terminal positions (get them from the datasheet; if unknown, say so and use a declared assumption).
2. Main path: busbar → main fuse (Class T or ANL, rating ≥ 1.25× continuous) → main contactor (≥ 300 A continuous at 48 V, with **precharge resistor + relay**, required because of UR OEM DC 400 A inrush) → distribution block.
3. Branches, each with its own fuse: 6× drive controllers, 2× UR OEM DC controllers, 1× DC-DC 48→24 V and 48→12 V (compute, sensors, fans), e-stop loop.
4. Drive controllers: WD220 needs an external controller — choose a real 48 V controller rated ≥ 47 A continuous (S2 nameplate), place one per corner near the drive (short phase leads) or centrally; justify.
5. Cable sizing (copper, ≤ 3 % drop, ampacity with ≥ 25 % margin):
   - trunk ~300 A → 70 mm² (2/0 AWG): 1 m out+back ≈ 0.49 mΩ → 0.15 V at 300 A.
   - each drive feed 47 A → 10 mm² (≈7 AWG): 2 m run out+back ≈ 6.9 mΩ → 0.32 V (0.6 %).
   - UR feeds per UR inrush/continuous data; DC-DC per its input current.
   Use `cad_stuff/generators/wire.py` (`route(awg, points, od)`) or equivalent sweeps with bend radius ≥ 6× cable OD. Routes go through the existing cable troughs and body pass-throughs, clipped every ≤ 300 mm.
6. Connectors: XT90 / Anderson SB per STANDARD for removable modules; M12 for outdoor signals; CAN-FD daisy chain to every drive controller + BMS.
7. Pass: an electrical connectivity table (JSON) where every load has a path battery → fuse → contactor → its fuse → load, every cable has gauge/length/drop, and every cable solid touches its two terminals in the connectivity check. Viewer shows the harness layer.

## Task C — viewer
1. Load `integration/drive_envelope_WD220.glb` at every corner (same transforms as the drive reservation; right corners via Rz(pi)), and the coilover once Task A passes.
2. Load the bearing envelopes (currently skipped in rover.js) or real bushing solids, so wishbones don't float.
3. Battery reservations visible by default with the harness layer; label "dimension-only" where true.
4. Pass: screenshot QA from all corners shows no visible gaps between wheel, drive, upright, arms, clamp, frame.

## Task D — body panels
17 body solids float 4–30 mm off supports (hatch/cover nodes). Add the fasteners/hinges/latches that hold them (nutplates + M6 screws are already provisioned) so each removable panel touches its holder. Pass: full connectivity run, 0 floating.

## Task E — flange protrusion regression (small)
Add a test: adapter grip = head-seat Z − UR face Z (R04: 11.5 mm); for the chosen ISO 4762 M8 length, protrusion = L − grip ≤ 7 mm (UR limit) and ≥ 4 mm engagement. Today only M8×16 (4.5) and M8×18 (6.5) pass. Fail CI if the selected length violates it.

## Task F — tire-change drone v0 (after A–C)
Design per `RHS059/cad_stuff/designs/tire_drone/MAINTENANCE.md` and `STANDARD.md`, from `cad_stuff` parts (wheels by size code, lug sockets/nuts, house LRU plate, NEMA/BLDC, fans, etc.). Every LRU ≤ 4 fasteners, ≤ 15 kg or lift points. Pass: connectivity 0 floating, DFM pass on all original parts, and a written test of each job step (jack, unbolt, lift wheel, swap, torque, inflate) with the forces from MAINTENANCE.md.

Report progress in the thread; Claude reviews each task with the checks above.

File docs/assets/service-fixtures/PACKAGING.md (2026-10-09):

# Published source layout

The original S01 source and geometry are retained. The verifier paths were adjusted to the adjacent mechanical, body-power, wheels and corners folders in this public asset package. No geometry was changed. The original S01 checks use C02_R05; the current C02_R06 entry-relief correction is strictly subtractive with identical poses and preserves these fixture clearances. Fixtures are static workholding studies, not rated lifting equipment or approved hardware.

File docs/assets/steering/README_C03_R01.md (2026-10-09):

# C03 R01: four-corner steering development CAD

This original design adapts independent suspension to the six-wheel rover. Front and rear corners steer through spherical-joint uprights and connected tie links; the middle two corners retain C02 R06 fixed uprights. The reference vehicle photographs depict a four-wheel vehicle and provide no manufacturing dimensions.

## Current deliverables

- `interface_contract_C03_R01.json`: authoritative frames, handed parts, motion groups, limits and open gates.
- `original_steering_C03_R01.step`: 76 named original component groups in vehicle coordinates, millimetres.
- `original_steering_C03_R01.glb`: matching named meshes, metres, Z-up. No implicit root rotation.
- `original_steering_C03_R01_manifest.json`: node/motion-group mapping and CAD-derived mass properties.
- `kinematics_C03_R01.js`: executable handed closure solver. Its inputs are suspension angle, rack translation, side and front/rear sign. Wheel yaw is an output, not an independent animation control.
- `mass_cost_ledger_C03_R01.json` and `original_parts_C03_R01.csv`: original fabricated-part subtotal and purchased components whose mass/cost remain unknown.

The assembly contains four original corner mechanisms and two racks. Frame, body, wheels and fixed middle corners are supplied separately. Purchased drive internals, bearings, spacers, rod ends, actuators and dampers are not invented or counted as solid material. The restricted drive STEP/PDF and derived meshes are absent.

## Geometry and checks

Wheel centres are X = −1.35, 0, +1.35 m, Y = ±0.94 m, Z = −0.25 m. The source tire diameter is 876.3 mm. Published 317.5 mm section width was measured on a 10-inch rim; the selected 8.5-inch rim's actual section is unknown. A separate solid 340 mm-wide annular reservation is tested.

The new rack travels ±75 mm. Tie eye spacing is 310.367524 mm. Both tie pins use inclined axes and the 12-10HB interface. The nominal 200 mm industrial actuator has 25–175 mm extension over that travel. Its suitability for steering is unresolved.

Completed, bounded checks include:

- 29,161 analytical closure cases, no closure or catalogue angular-screen failures.
- 74 sampled upright, arm, pin and retainer Boolean checks, zero positive intersections.
- Rack, liner, clamp, fastener, body and frame checks at −75, 0 and +75 mm, zero positive intersections.
- 36 combined poses against the body/frame for both the original wheel CAD and the separate 340 mm tire reservation, zero positive intersections.
- Sampled tie/fork envelopes: minimum 6.637 mm at the inner rod-end housing reservation.
- Revised lever: 6.439 mm to the reserved tire and 8.747 mm to the moving lower arm in the tested samples.
- S01 static fixture compatibility at zero suspension/rack input: 88 checks of the 76 actual baked nodes plus 12 conservative reservations against 302 fixture solids, zero interference; closest conservative tie reservation gap 8.062 mm.

These are unloaded nominal-geometry results. They do not establish continuous swept clearance, tolerance/deflection margin, dynamics, structural strength, or safe operation. The current private-drive fit review is recorded separately in the contract when available.

## Mass and actuation

The four original steering corners and two racks total 238.204930 kg using the stated density assumptions. Including the two fixed middle corners gives 328.887508 kg of original running-gear material, 56.839774 kg above C02. This is not the complete vehicle mass. EVO nut weight metadata has unverified units and is excluded.

An illustrative 1500 kg, equal-wheel-load, friction-coefficient 0.6 screen produces 2.226 kN static rack force and 6.678 kN with the same friction model at 3g. It omits contact-patch torsion and losses. The 4.5 kN B045 actuator therefore remains a packaging candidate; its 25% duty and approximately 7.9-second rated-speed lock-to-lock time also need application review.

## Build and service gates

No fabrication or operation release is issued. Required work includes:

1. Finished bearing fits, spacers, preload, retainers, pins, thread classes, weld processes and fastener stacks.
2. Steering actuator force/speed/duty, sensing, endplay, fault response and stop-load qualification.
3. Exact coilover mounting drawing, spring selection, damping/thermal performance, reservoir routing and bump/rebound limits.
4. Adapter stud/nut/tool access and fatigue. The 30 mm adapter currently leaves zero nominal input-stud-tip stand-off to the rim pad.
5. Simultaneous wheel, bearing, braking and steering loads; structural deflection, buckling, fatigue and weld assessment.
6. Supported service sequence with stored spring energy controlled. S01 compatibility applies only at the neutral pose. The earlier long pin corridor intersects the installed tire; wheel-first or another accessible release sequence must be proven with the actual tools. No autonomous repair sequence is established.

## Reproduction

Use CadQuery 2.7.0 and the repository's original `generate_cad.py` helper. Frozen source generators include `generate_steering_corner.py`, `generate_spherical_housing.py`, `add_steering_lever.py`, `generate_rack_R11.py`, `generate_rack_mount_interfaces.py`, `generate_tie_link.py`, `generate_tie_pins.py`, `bake_rear_steering_parts.py` and `build_original_steering_assembly.py`. They depend on the stated original C02 source parts. Run the version-labelled test scripts and regenerate their reports after any dimensional change. Historical rejected revisions remain distinguishable by filename; never combine their tests with this checkpoint.

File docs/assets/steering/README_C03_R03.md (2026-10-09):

# Original rover steering C03 R03

This is an original six-wheel rover adaptation, with four steerable corners and two fixed middle corners. The selected assembly contains four upper R06 arms, four lower R04 arms, the unchanged handed carriers, and two R11 guided racks. The 76-node assembly excludes purchased drive internals, bearings, shocks and actuators. STEP units are millimetres; GLB units are metres, vehicle X forward, Y left, Z up.

## Current scope

The R03 contract and manifest select the current geometry. Earlier R01-named sources and reports in this package are retained dependencies and historical regression evidence. C03 R02 was rejected because upper R03 touched the tire. Intermediate upper R04 failed the 340 mm reservation; upper R05 touched a root clevis. R06 changes the original tube routes while retaining every joint center and the existing kinematic solver.

Normal display starts at suspension q = 0. After final export binding, an explicitly labeled unqualified motion-study mode may expose q within ±12° and racks within ±75 mm. Front and rear racks may be posed independently; workshop fixtures require suspension and both racks at zero. Sampled geometric clearance does not qualify loaded motion, ground contact, tire deformation, spring/damper behavior, structural strength or safe operation. Approximately 3 mm nominal local margins are unqualified for tolerances, weld distortion and deflection.

## Reproduction

Use Python 3.11, CadQuery 2.7.0, NumPy and SciPy from the normal package registry. Preserve this directory tree. Frozen geometry bytes and the public SHA256 whitelist are authoritative; new OpenCascade exports can differ in bytes.

From mechanical/running_gear_C03, the baseline generators retain their original output names. Generate baseline dependencies in the R01 sequence if needed, then run generate_upper_wishbone_R06.py and generate_lower_wishbone_R04.py, build_original_steering_assembly_R03.py, write_mass_ledger_C03_R03.py, and check_export_C03_R03.py. The selected contract is interface_contract_C03_R03.json. Its source builder deliberately starts with pending checks; finalize_contract_C03_R03.py binds the completed evidence after verification. The unchanged executable solver is kinematics_C03_R01.js. The final release evidence list identifies current tests; historical tests alone cannot establish R03 fit.

Changed-arm checks are under steering_optimization/travel_arm_U06_L04. They use the included original frame, body, wheel and fixture STEP files. Motor fit reports are numerical evidence from restricted vendor geometry; that geometry is deliberately absent, so those checks require separately authorized access to the exact source hash. No OEM CAD, PDF or derived mesh is in this archive.

## Remaining engineering gates

No fabrication, operation, lifting or autonomous repair release is granted. Open items include finished tolerances, bearing/spacer profiles and retention, weld process and fatigue, wheel stud/nut/tool stacks, drive bearing loads, steering force/speed/duty and fault behavior, shock/spring selection, tire size on the selected rim, loaded ground contact, and collision-free service access. The installed tire blocks the previously proposed long pin-withdrawal corridor; static fixture clearance is not a removal procedure.

The mass ledger is an original-CAD subtotal under stated density assumptions. Unknown purchased masses and prices remain null. The EVO nut's raw catalogue weight has no verified unit. Actuator comparison is a bounded sourcing study, not a changed or qualified hardware selection.

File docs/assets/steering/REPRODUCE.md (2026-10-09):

# Reproduce C03 R01

Use Python3.11, CadQuery2.7.0, NumPy and SciPy. Install from the normal package registry in an isolated environment. Keep the directory tree intact.

The frozen STEP/GLB files and public whitelist are authoritative. Source copies have only documented local-path normalization; their native and packaged hashes are both listed. No geometry bytes are changed. The R10 carriage test is pointed at R11 because the carriage is identical; only the stationary guide and liners changed.

In mechanical/running_gear_C03, regenerate in order: generate_spherical_housing.py; generate_steering_corner.py; generate_outer_pins.py; add_steering_lever.py; generate_rack_mount_interfaces.py; generate_rack_R11.py; generate_tie_link.py; generate_tie_pins.py; bake_rear_steering_parts.py; build_original_steering_assembly.py; write_mass_ledger_C03_R01.py. C02 source inputs are included.

Run verify_steering_closure.py, check_corner_steering_R05.py, check_rack_assembly_R11.py, check_full_wheel_sweep.py, check_reserved_tire_sweep.py, check_actuator_reservations.py and check_rack_force_screen.py. Independent checks are under steering_optimization. Kernel-generated STEP bytes can differ on regeneration; compare geometry and reported interfaces rather than requiring byte equality of a newly exported STEP.

The published max-body actuator envelope record was originally acquired for the150mm candidate. The current200mm design uses the same B045 body family with source pin-length law A=stroke+190mm; the final contract controls its490mm neutral length. No exact actuator order configuration or profile approval is asserted.

All tests are engineering-development checks, not strength/fatigue/safety approval.

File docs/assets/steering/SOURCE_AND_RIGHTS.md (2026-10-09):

# Source and rights notes

All included STEP/GLB geometry is original project CAD. Commercial product names and interface dimensions identify external sources; they do not imply manufacturer approval. No proprietary WD220 or Robotiq STEP/PDF, derived vendor mesh, full catalogue, downloaded image, or credential is included. Source links and bounded dimensional facts are in the source JSON records. This package does not grant rights to separately sourced manufacturer assets.

Original body, wheel and fixture models are included only as exact test dependencies. They retain their documented dimensional/material assumptions and qualification limits.

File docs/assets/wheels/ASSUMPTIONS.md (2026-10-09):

# Wheel C01 assumptions and limits

This is an original, source-backed parametric fit-development model. It is not manufacturer CAD, reverse-engineered OEM detail, a manufacturing drawing, or approved hardware. It deliberately does not reproduce the KM3 tread or EVO Corse paired-spoke design. No manufacturer logo, lettering, scan, downloaded wheel mesh, or proprietary CAD was used.

## Published dimensions used directly

- Tire selection: BFGoodrich Mud-Terrain T/A KM3, MSPN 72204, 35x12.50R18/E 123Q.
- Published overall diameter 34.5 in (876.3 mm), section width 12.5 in (317.5 mm), measured on a 10 in rim. Permitted rim width 8.5–11 in. Tread depth 18/32 in (14.2875 mm).
- Rim candidate: EVO Corse DakarZero SE5240060141, 18 x 8.5 in. Nominal bead-seat diameter 457.2 mm and width 215.9 mm. Offset +18 mm, five mounting holes on a 165.1 mm pitch circle, nominal center bore 114.1 mm. Flat nut seats.
- Published matching nut CM0750180040: M16x1.5, flat washer, 27 mm hex, 51.5 mm overall length and 38.5 mm exterior diameter. Nuts are not included in this asset.

## Provisional envelope

The tire dimensions above were measured by its manufacturer on a 10 in rim. This model changes bead spacing to 8.5 in while retaining those published outside dimensions as an explicitly provisional fit envelope. Actual inflated width, OD, sidewall shape and loaded radius on the selected rim must be measured or obtained from the manufacturer. Retaining the published dimensions does not establish conservatism. The nominal 35 in size is not used as the measured diameter.

## Original assumed construction

- Bead, sidewall, inner cavity, ply/cord omission and crown shape are original simplified geometry. They do not establish air sealing, pressure retention, wear, stiffness or bead retention.
- Tread is 160 original annular-sector blocks, four rows of 40. Pattern, block width, gaps, shoulder treatment and carcass thickness are assumptions. Only nominal radial depth is derived from the databook.
- Rim dropwell, hump, flange height and thickness, barrel thickness, perforated dish, vent holes, all fillets and final mass are unknown. The original five-window dish is intentionally different from the OEM paired-spoke appearance.
- Model flange height 16 mm, flange axial thickness 7 mm, barrel wall about 8 mm. These are construction assumptions, not J-profile/ETRTO compliance claims.
- Lug clearance holes are assumed 18 mm. The mounting pad is assumed 20 mm thick; its inboard face is y=18 mm and outboard flat washer seats are y=38 mm. Hole size, actual washer bearing area, pad thickness, stud projection, thread engagement and fit tolerances remain unverified.
- Lug phase 36 degrees in the XZ plane, measured from +X toward +Z, is an original integration choice to alternate with the drive adapter's input pattern. It has no OEM significance.
- No valve, beadlock, fasteners, finish thickness, casting draft, porosity, air channels, stamping, tire cord, balance weights, fillet stress concentrations or manufacturing tolerances are modeled.

## Assembly contract

Wheel center is the origin; +Y is axle/outboard, X forward and Z up. Left wheel mounting plane is local y=+18 mm. On the right side use a proper 180 degree rotation about Z, followed by translation. No reflected geometry or source scaling is allowed. GLB contains metres with the stated Z-up engineering convention; STEP and native source use millimetres. The GLB has separate tire and rim nodes.

A WD220 drive has a different five-hole 140 mm PCD and 94 mm pilot. It cannot directly fit this rim. The separate original adapter model must handle the mismatch. This asset includes no adapter and does not certify it. Nominal bore contact is not a finished fit specification.

## Ratings and release gate

The databook lists 3415 lb at 75 psi for the selected tire. The exact official rim page lists 1400 kg per wheel. Those are catalog component ratings under their stated conditions, not ratings of this original geometry, adapter, hub, suspension or complete rover. The model has not been structurally analyzed or certified. Do not manufacture or order an adapter from this fit model without supplier drawings, measured fit checks, fastener design, load cases, pressure safety and engineering review.

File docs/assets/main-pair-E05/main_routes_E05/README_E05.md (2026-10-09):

# E05: two supported main DC cable routes

This original module closes only the geometric jacket routes from Q0:P_OUT to LYNX:BAT+ and Q0:N_OUT to LYNX:BAT−. It is a non-energizable installation candidate. It does not close battery-to-Q0 wiring, upstream protection/merge, traction branches, motor pigtails, arm wiring, control mapping, safety permissions or regeneration handling.

## Integration

Load main_pair_supported_E05.glb with the same placement as E04. GLB vertices are already in metres with Z up; STEP and contract coordinates are C millimetres. Do not apply an additional millimetre-to-metre scale to the GLB. Replace exactly controller_battery_partition and battery_tool_partition with the two names in partition_main_glands_E05.glb. Preserve the forty-hole deck and all other selected body parts. Remove optional old Q0_P_OUT_service_lead_bend and Q0_N_OUT_service_lead_bend overlays. The other E04 local open lead segments remain unfinished overlays.

All 98 added source nodes appear in main_pair_graph_E05.json: two continuous jacket envelopes, eight original stands and sixteen clamp halves, sixty-four M4 stack components, four source-sized glands and four locknuts. Nominal cylindrical threads model retained contact without helical thread strength claims. Original stand feet contact the actual deck. The intended joint is aluminium-to-matched-aluminium welding; exact deck/stand alloy, temper, filler, heat-affected-zone and thin-deck strength qualification remain open. Mere bearing does not establish a commissioned welded load path.

## Evidence and limits

Actual STEP checks cover the composed body/electronics, all new self-pairs, source-positioned original lug mouths, support/clamp/retainer contacts, four full partition bores and all cable segment seams. Separate checks cover 78 sampled corner poses against R13 towers and guided shock modules. These are finite-pose geometry checks, not dynamic flexible-cable, continuous-motion, tool-access or service validation.

LAPP ÖLFLEX HEAT 180 SiF 0060001 provides the 70 mm², nominal 14.2 mm OD and fixed-installation 6D bend dimensions. Exact CAD arcs reach the nominal 85.2 mm minimum; actual OD tolerances still require release. The model renders silicone insulation envelopes, with no conductor strands or qualified crimp interface. Positive identification, cable thermal rating, abrasion protection and gland sealing/pullout remain open. The source black cable is not a moving-corner harness selection.

cable_source_and_scenario_E05.json contains source provenance and a declared ideal-copper 180 A scenario. The proposed bank cap is unenforced; calculated loss is not ampacity or protective-coordination approval. Upstream pack fuses, covered merge hardware and main-fuse coordination are absent. Do not energize.

Battery polarity uses the separate R01 correction: positive Y+275.25, negative Y−275.25. E05 itself connects no battery terminal. Motor connector XYZ remain unknown.

## Public scope

PUBLIC_FILES_E05.json is the only allowlist. Included CAD and scripts are original work. Supplier CAD/PDF/images, rejected revisions, review images and logs are excluded. E04 is immutable and supplied separately. The existing C04 cost freeze excludes this new E05 module; its cable-length estimate must not silently enter an accepted whole-vehicle subtotal.

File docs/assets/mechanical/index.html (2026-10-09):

# Original frame and tool adapter

New parametric CAD, not manufacturing release. See the qualification record before using any model.

- Qualifications and unresolved physical checks
- Frame R07 STEP
- Adapter R04 STEP
- Parametric source
- Frame verification
- Adapter verification
- Interface contract
- Tool-adapter source
- Frame manufacturing-geometry screen
- Adapter manufacturing-geometry screen
- Independent checker attribution

R07 is a lighter unqualified structural candidate. R04 enlarges the tool-adapter counterbores. The linked original qualification record retains prior revision history; current part reports state current dimensions.

Back to viewer

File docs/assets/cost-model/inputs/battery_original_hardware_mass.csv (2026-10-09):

part | group | volume_mm3 | assumed_density_kg_m3 | mass_kg
BA02_pack_1_tray_M8_1_top_washer | battery_fasteners | 233.0307766726767 | 7850 | 0.0018292915968805123
BA02_pack_1_tray_M8_1_screw | battery_fasteners | 2445.1151324914895 | 7850 | 0.019194153790058194
BA02_pack_1_tray_M8_1_bottom_washer | battery_fasteners | 233.03077667267655 | 7850 | 0.001829291596880511
BA02_pack_1_tray_M8_1_nut | battery_fasteners | 624.6032700838738 | 7850 | 0.00490313567015841
BA02_pack_1_tray_M8_2_top_washer | battery_fasteners | 233.0307766726767 | 7850 | 0.0018292915968805123
BA02_pack_1_tray_M8_2_screw | battery_fasteners | 2445.1151324914895 | 7850 | 0.019194153790058194
BA02_pack_1_tray_M8_2_bottom_washer | battery_fasteners | 233.03077667267655 | 7850 | 0.001829291596880511
BA02_pack_1_tray_M8_2_nut | battery_fasteners | 624.6032700838738 | 7850 | 0.00490313567015841
BA02_pack_1_tray_M8_3_top_washer | battery_fasteners | 233.03077667267686 | 7850 | 0.0018292915968805136
BA02_pack_1_tray_M8_3_screw | battery_fasteners | 2445.115132491493 | 7850 | 0.019194153790058222
BA02_pack_1_tray_M8_3_bottom_washer | battery_fasteners | 233.03077667267684 | 7850 | 0.0018292915968805134
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

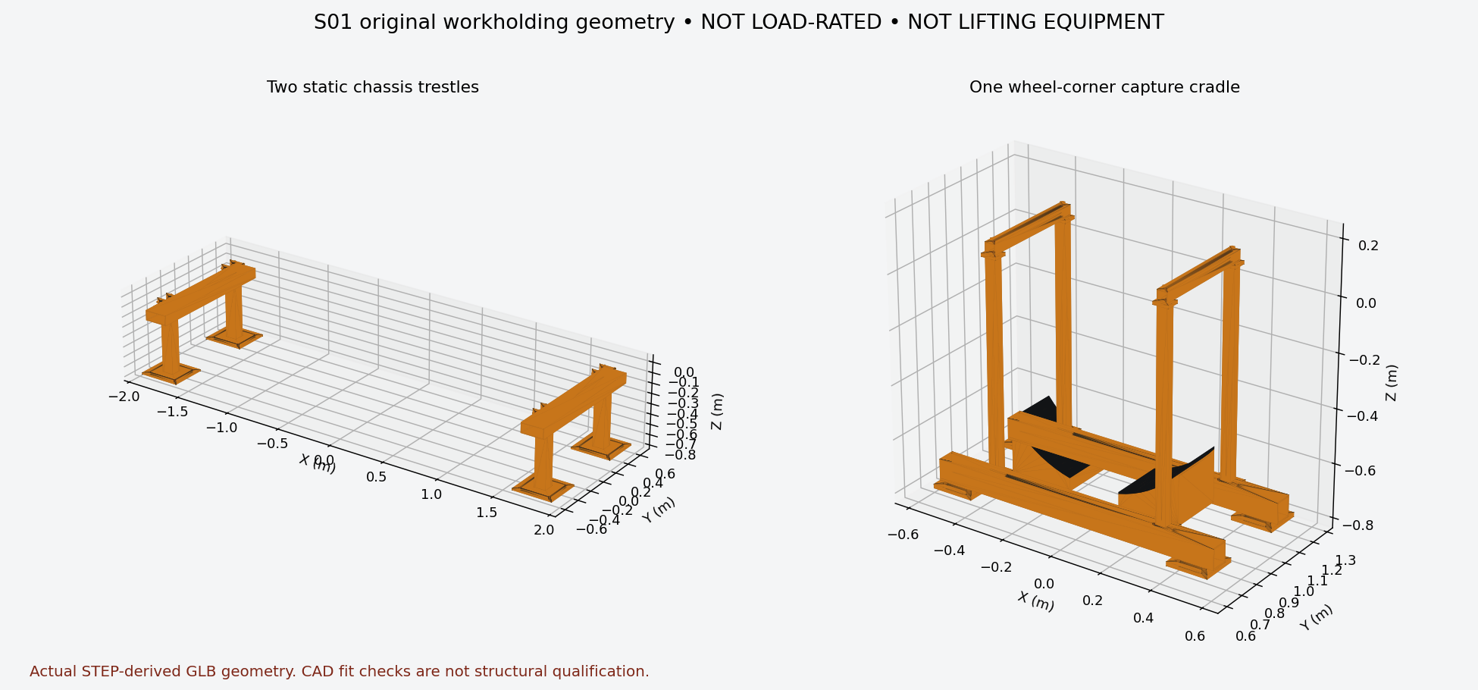
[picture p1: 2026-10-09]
docs/assets/service-fixtures/service_fixtures_S01_preview.png

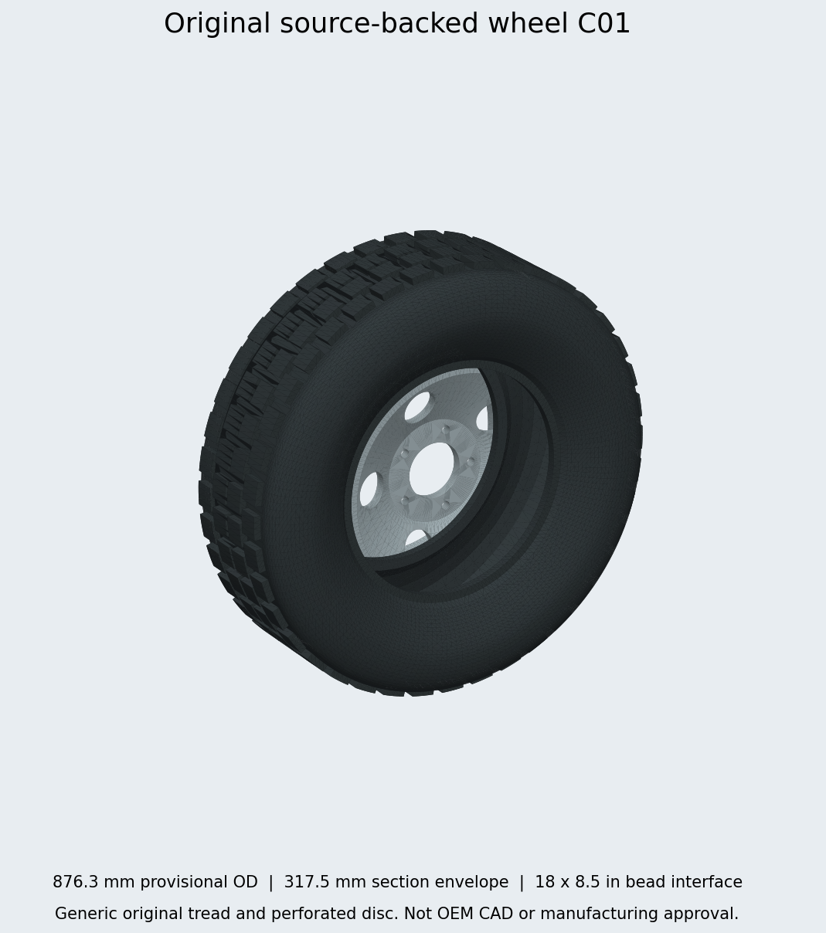
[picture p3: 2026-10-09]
docs/assets/wheels/wheel_C01_preview.png

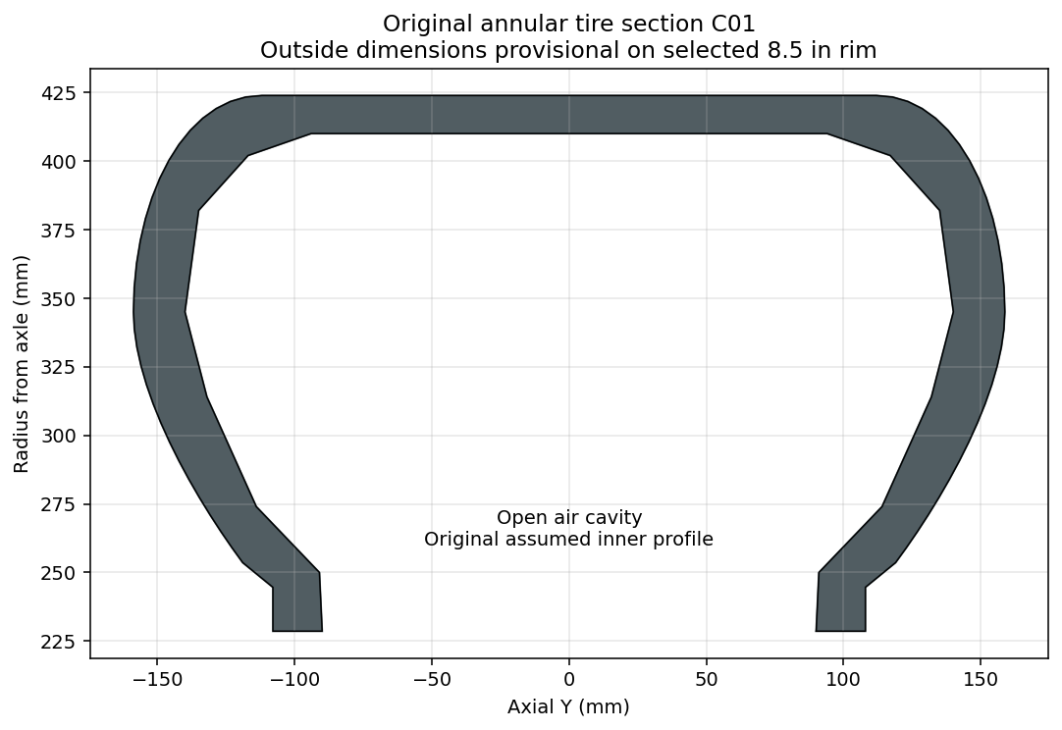
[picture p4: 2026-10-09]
docs/assets/wheels/tire_C01_section.png

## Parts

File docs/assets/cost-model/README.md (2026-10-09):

# C04 + E05 separate mass, BOM and cost candidate

Prepared 9 October 2026. This is an isolated, offline-reproducible candidate patch. It does not change `app-C04`, the accepted `cost-model-C04` snapshot, the E05 source freeze, or the pending publication payload. No external write, order, supplier contact or publication is included.

## Result

| Known nominal subset component | Delta, kg |
|---|---:|
| Two LAPP 0060001 geometric route lengths | +4.074692045393900 |
| Eight original aluminium stands | +0.427410760119472 |
| Four holes in two existing aluminium partitions | −0.016159799689731 |
| **Net known-subset delta** | **+4.485943005823641** |
| C04 baseline known subset | 1268.064164099253700 |
| **Separate C04+E05 candidate known subset** | **1272.550107105077600** |

These are mixed nominal modeled/catalogue estimates, not weighed or complete installed masses. Full E05 installed mass, whole-vehicle mass, center of gravity and complete build cost remain unknown. Tiny last-digit differences from direct bore-volume arithmetic reflect floating-point summation only.

The priced subsets remain **USD 17,200** and **PLN 6,090**, separately and with the original dated/mixed-market restrictions. None of the 98 new rows has an accepted price. A zero change in priced subsets does not mean E05 is free. No currency conversion, raw-metal price, fastener allowance, cable allowance, gland price or labor estimate has been invented.

Actual operating cost/hour and runtime remain null. The entire C04 operating-cost object is preserved exactly: its 2/4/8 kW assumptions and illustrative partial USD/hour figures are unchanged. Added mass and an ideal-copper route-loss scenario do not justify a new measured demand or runtime claim.

## Cable source, lengths and boundaries

The [official LAPP ÖLFLEX HEAT 180 SiF catalogue](https://products.lappgroup.com/online-catalogue/power-and-control-cables/expanded-ambient-temperatures/silicone-single-cores/oelflex-heat-180-sif.html) was checked on 9 October 2026. The exact article 0060001 row gives 70 mm², black insulation, 14.2 mm nominal OD, and nominal cable weight 724 kg/km, equivalent to 0.724 kg/m. The adjacent 672 kg/km value is the separate copper index; it is not the full cable mass. Manufacturer values are nominal, with detailed tolerances available on request.

The frozen geometry supplies the lengths, not the manufacturer:

- MAIN_positive, Q0:P_OUT → LYNX:BAT+: 2.7697464313510465 m
- MAIN_negative, Q0:N_OUT → LYNX:BAT−: 2.8582812556571024 m
- Total 5.628027687008149 m × 0.724 kg/m = 4.0746920453939 kg

This is a nominal routed-length cable estimate. Procurement cut lengths are unreleased and remain null. It excludes additional stripping/cut allowances, slack or service allowance beyond the modeled routes, waste, new terminations and other hardware. Cable jacket volumes are never multiplied by copper, silicone or other bulk density; doing that as well as applying catalogue mass would double count the cable.

Two geometric jacket routes are present. Conductive crimp contact, installed ampacity, protection coordination, upstream pack/merge/main-fuse wiring, traction branches, motor pigtails, arm wiring, safety mapping and regeneration handling are still unresolved. End-to-end electrical continuity and operational acceptance remain false. Do not energize. The source's 180 A ideal-copper calculation is preserved in the frozen evidence only; it is not injected into operating scenarios or treated as ampacity approval.

## Exact part accounting

`replacement_map.json` records full old/new named body records and masses:

| Body name | Old kg | Replacement kg |
|---|---:|---:|
| controller_battery_partition | 1.9023945235218704 | 1.8943146236770079 |
| battery_tool_partition | 1.9677206001606726 | 1.9596407003158060 |

Only these two existing parts are replaced. Each loses two 25.2 mm bores through 3 mm material. They remain included once through the single `body_composed` BOM row. All other 235 final body records, including the forty-hole `main_base_deck_3mm`, are unchanged. The final body still contains 237 named records; its known original mass is 113.53953045712207 kg.

There are 98 added source nodes and exactly 98 added BOM rows, for 328 rows total. Source nodes are individually traceable to the contract, connection graph and GLB:

- 2 cable runs: nominal manufacturer mass × source geometry length accepted
- 8 original welded stands: 2700 kg/m³ assumed aluminium density matched to the retained deck
- 16 original clamp halves: mass and material/liner selection unknown
- 16 M4×30 screws, 32 washers and 16 M4 nuts: purchased SKU, installed mass and price unknown
- 4 LAPP 53111030 glands and 4 LAPP 53119030 locknuts: installed mass and price unknown

The eight stands add 0.4274107601194724 kg of nominal original aluminium. The E05 generator's legacy `steel` display-palette key is explicitly rejected as a material specification. An exact-name material ledger binds each node to the frozen contract's `actual_material`, then accepts only the declared aluminium density for stands. Alloy, temper, filler, weld process, heat-affected-zone strength and fatigue remain unqualified. Original clamp material is not assigned a guessed polymer density. Nominal steel fastener geometry is not used to invent commercial masses.

Existing E04 lugs and M8/M10 terminal stacks are reused without an extra mass or purchase term. Optional old Q0_P_OUT_service_lead_bend and Q0_N_OUT_service_lead_bend were absent from both the frozen runtime source-node selection and accepted C04 mass ledger. They are neither added nor subtracted here. Their conditional removal list is recorded explicitly. Remaining-harness scope excludes already itemized E05 rows and reused terminal hardware.

## Reproduce and inspect

Use Python 3 with only its standard library:

```sh
python build_cost_model.py
python test_cost_model.py
```

Normal replay is offline, uses only bundled inputs and writes only this folder. No CAD kernel, browser, upstream directory or external service is required. The builder refuses altered frozen inputs. It also verifies the original C04 checksum set, E05 public allowlist and freeze pins before calculating. The prior C04 builder can reproduce its model in an isolated temporary copy.

The 36 regression tests cover input hashes, actual GLB node names, exact replacements, unchanged deck/body rows, bore arithmetic, explicit aluminium materials, null commercial parts, cable units, no duplicate optional leads, reused terminal hardware, row counts, mass/baskets, identical scenarios, null actuals, electrical scope, CSV roundtrip, deterministic replay and rejection of a tampered input. They are calculation/source-accounting tests, not independent CAD-kernel, metrology, structural, electrical, procurement or operational approval. Frozen upstream geometry-check reports are evidence from the E05 source freeze; their CAD analyses were not rerun for this cost patch.

Key files:

- `cost_model.json`, `BOM.csv`, `sources.json`: separate complete candidate cost/BOM data
- `delta_summary.json`: small machine-readable numerical change and unresolved boundaries
- `body_composition.json`, `replacement_map.json`: exact final body and replacements
- `material_mass_ledger_E05.json`: all 98 added named nodes with explicit material/mass decisions
- `mass_reconciliation.json`: full final mass rows and groups
- `input-manifest.json`: 76 immutable local input files and SHA-256 pins
- `dependency_manifest.json`: E05 freeze/geometry pins plus 12 verified separately supplied upstream dependencies
- `output-checksums.json`: deterministic generated-output hashes
- `validation.json`, `test_run.log`: local regression results
- `isolation_verification.json`: source/app/publication comparison against the pre-build read-only snapshot
- `UI_INTEGRATION.md`: future integration handoff; no app changes have been made

`inputs/C04/` preserves the prior model and its complete factual input package. `inputs/E05/` contains only the E05 public allowlist plus its freeze/allowlist records: original CAD, scripts and factual ledgers, no supplier CAD/PDF/images. `inputs/runtime_C04/` records the frozen runtime loader/selection used for the optional-lead check. Manufacturer provenance is a compact factual observation with a direct source link, not a copied webpage.

The 12 upstream geometry dependencies are hash-pinned and were checked against their actual local bytes. They remain separately supplied and are not required to replay this mass calculation; a CAD regeneration would require them and the E05 CAD toolchain. `freeze_inputs.py` is a maintainer-only one-time snapshot tool, deliberately refusing an existing freeze. Do not use it to silently update sources during replay.

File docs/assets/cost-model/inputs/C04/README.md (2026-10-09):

# C04 matched build and operating cost model

Observed 9 October 2026. Development visualization only, not fabrication, procurement or operational release. This package changes no application files and makes no orders or vendor contacts.

## Results

- **Complete build cost is unknown.** The matched BOM contains 230 cost/mass rows, including original geometry and unresolved categories. This is not a complete manufacturing BOM.
- **Priced subset: USD 17,200 and PLN 6,090, kept separate.** No EUR rim basket survives. USD combines US gripper/coupling references with a clearly dated 2026 Q2 LATAM USD-C battery/BMS price list; these are not a current US quotation or a common landed-cost basis.
- **Known modeled/catalogue mass subset: 1268.0641640992537 kg.** Whole-vehicle mass and center of gravity remain unknown. No vehicle was weighed.
- **Actual hourly operating cost and runtime are unknown.** Preserved illustrative 2, 4 and 8 kW assumptions now use the selected 10.24 kWh nominal bank and USD 4,482 dated module-only replacement reference. Partial scenario results are USD 61.23, 61.76 and 63.52 per operating hour. These omit major costs and do not establish continuous operation.

## Price observations

| Selected item | Quantity | Unit reference | Extended reference | Basis |
|---|---:|---:|---:|---|
| Robotiq AGC-GRP-2F85 | 2 | USD 5,205 | USD 10,410 | Retained [Logic public listing](https://www.logic-control.com/robotiq-agc-grp-2f85); exact contents/lead time require confirmation |
| Robotiq GRP-CPL-062 | 2 | USD 644 | USD 1,288 | Retained [King Barcode listing](https://www.kingbarcode.com/GRP-CPL-062); controller-connected route, full cable/interface cost absent |
| Victron BAT548110620 | 2 | USD 2,241 | USD 4,482 | [Official 2026 Q2 LATAM USD-C price list](https://latam.victronenergy.com/wp-content/uploads/2026/04/Pricelist-Victron-2026-Q2-USD-C.pdf), ex VAT, dated indicative reference |
| Victron LYN034170310 | 1 | USD 1,020 | USD 1,020 | Same dated LATAM price list, ex VAT |
| Trelleborg SK-900 12-16.5 12PR, seller SKU 35546 | 6 | PLN 1,015 | PLN 6,090 | [TyreTrade listing](https://tyretrade.pl/opona/12-16-5-trelleborg-sk-900-12pr/), gross/brutto; manufacturer article identifier and six-unit allocation unverified |

Jantsa 10005240 rim price remains null. NRS 60027.01.112 is a four-foot Stealth Black retail pair, so two packages supply four straps. Its variant-specific price and purchased mass remain null; the family range is not used. No tax, import charge, freight, FX rate, current stock allocation or supplier quote is invented. Confirm commercial region, exact SKUs, package contents and destination costs before procurement.

## Matched configuration

- Mechanical structure C04 R05, bound to the 575-file public source freeze C04 R02: 126 original nodes, replacing old C03 steering and C02 middle structures. No EVO/BFG or pattern-adapter active rows remain.
- Six Jantsa 10005240 9.75 x 16.5 ET -70 rims, six Trelleborg SK-900 tires, thirty RIMA 22095 nuts.
- Two Thomson B068 200 mm M/M candidates at 7 kg each; six Eibach 1800.300.0200S springs at 3.54 kg each. Their simplified external CAD does not add another mass term.
- Frame R07, two UR20 arms, two original R04 adapters, two Robotiq grippers and controller-connected couplings retained. The exact arm/controller package remains unpriced and must count packaged controllers only once.
- Body is PR01, then the twenty SO02_E04P named replacements, then the nineteen-part E04 trough/gland delta, then BA02 removes thirty-four RELiON restraint parts and replaces the well floor.
- BA02 has two 37 kg Victron batteries. Its original metal additions are counted separately from the replacement floor. Strap, buckle, battery, terminal and vent external depictions do not contribute density-based mass.
- Selected E02 carrier and E04 electrical patches compose by their ledger's remove/replace flags. Trough mass is in body only. Purchased housing, lug and connector-contact representations remain excluded from accepted original mass. Current [Lynx 1000 A specifications](https://www.victronenergy.com/media/pg/Lynx_Smart_BMS_NG/en/technical-specifications.html) give 2.7 kg; the conflicting 2.5 kg price-list value is not used for mass.

## Mass reconciliation

| Separate group | Included known kg |
|---|---:|
| Frame R07 | 386.9529671773959 |
| Two arms, two controller reservations, two original adapters | 139.233693246 |
| Original structure C04 R05 | 347.912332809332 |
| Original joint details | 14.017320451359337 |
| Original shock/carrier/retention details | 16.93926994842406 |
| Six rims + two actuators + six springs | 152.24 |
| Composed original body, including replacement well floor | 113.5556902568118 |
| BA02 new original metal excluding floor | 7.2705448374377335 |
| Two battery modules | 74 |
| Lynx BMS | 2.7 |
| Selected original electrical support/hardware estimates, excluding trough | 13.242345372493395 |

`body_composition.json` preserves every final named body part, material assumption, volume and mass; records the removed parts; and records each intermediate subtotal. PR01 material changes to aluminium bosses/clips are sourced from its generator instead of incorrectly inheriting the old steel placeholder material. Its progression is:

1. PR01: 267 parts, 116.7967822162259 kg
2. SO02_E04P: 267 parts, 115.99386426207543 kg
3. E04 trough/glands: 271 parts, 115.88551866207544 kg, with four unknown-mass purchased representations
4. BA02 removals/floor: 237 retained body parts, 113.5556902568118 kg

The BA02 additions are separate: 7.2705448374377335 kg original metal plus 74 kg battery catalogue mass. Its replacement floor is 3.7848881760772164 kg and appears only in the composed body.

The installed mass of drives, tires, nuts, dampers, bearings, grippers/couplings, straps/buckles, unselected-grade guides, inverter variants, ABB devices, most electrical components and harness remains unresolved. Original nominal hardware estimates do not prove final purchased mass, grade, preload, tolerance or fatigue strength.

## Operating boundaries

The bank is **2 × 51.2 V × 100 Ah = 10.24 kWh nominal**. Usable energy and mission energy are unknown. The **180 A figure is a conditional warm-bank development ceiling with no implemented vehicle enforcement**, not qualified full-six-motor operation. Actual BMS discharge/charge limits, both module temperatures, current sharing, auxiliaries, inrush and pack availability can reduce the permissible power or disable motion. ATC/ATD mapping, regen inhibition, an independent brake/energy sink, branch protection and completed physical wiring remain open.

The 47 A drive nameplate value is not established DC demand. Six 2.2 kW ratings are S2 60 minutes, with S1 unknown. Even ideal 13.2 kW/51.2 V is 257.8125 A before arms/auxiliaries and conversion losses; this is a limiting arithmetic illustration, not a system demand measurement.

Preserved assumptions are USD 0.15/kWh, 90% charging efficiency, one supervisor hour at USD 50 and 0.1 maintenance hour at USD 100 per robot-hour; 2,000 cycles, 80% depth, five calendar years and 1,000 operating hours/year. The module reserve takes the larger of cycle or calendar reserve, never their sum. Only the module reference changes to USD 4,482 and nominal capacity changes to 10.24 kWh. These life and utilization assumptions are not validated. The BMS is not included in the module-only reserve. Capital, replacement installation labor, maintenance parts, taxes/freight, insurance, consumables, connectivity, transport, parked energy and downtime remain excluded.

## Reproduction and files

Run `python build_cost_model.py` then `python test_cost_model.py` in this directory. Both use the Python standard library. The builder needs only the bundled frozen inputs, performs no network calls and is byte-reproducible. The 24 passing tests cover arithmetic, CSV, null preservation, source hashes, replacements, quantities, thermal/control flags, no-proxy/double-counting and deterministic rebuild. They are not hardware or safety tests.

- `cost_model.json`, `BOM.csv`, `sources.json`: active matched cost model
- `mass_reconciliation.json`, `body_composition.json`, `electrical_mass_selection.json`: inspectable accepted/excluded mass evidence
- `inputs/`: factual frozen ledgers, baseline historical records and one original source script for material traceability; no vendor CAD, PDFs or fetched webpage captures
- `input-manifest.json`: exact source-file and SHA-256 mapping
- `validation.json`, `test_run.log`: local checks
- `UI_INTEGRATION.md`: required static-text changes when the parent integrates this model

`freeze_inputs.py` is a maintainer-only refresh tool for the original shared staging paths. It is not part of normal replay. Do not run it to silently follow new files: inspect the changes, refresh deliberately, rerun tests and update checksums. Historical C03 data is preserved solely under named historical input records and is not included in active totals.

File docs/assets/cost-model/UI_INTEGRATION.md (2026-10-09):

# Future integration handoff, not an app change

This folder is a separate C04+E05 candidate. Keep it outside the current app/publication payload until the parent deliberately chooses the matching geometry and model revision. The existing C04 app still correctly carries its prior C04-only known subset; do not silently advertise these E05 numbers against a scene that lacks E05.

For a later matched integration:

1. Preserve the 40-hole deck and every body part except the two exact names in `replacement_map.json`. Replace those parts; do not add duplicate old/new partitions.
2. Load the 98-node E05 main pair once. Its GLB is already in vehicle-C metres; no second mm-to-m conversion. Only two geometric jacket routes are closed. Keep physical electrical continuity false.
3. Use the new single `body_composed` row plus 98 individually named E05 rows. Existing E04 lugs/stacks remain counted once. Optional old local leads were not loaded or mass-counted; there is no subtractive mass correction for them.
4. Show `1272.5501071050776 kg` only as the known modeled/catalogue subset, never full installed vehicle mass. Explain that this includes unreleased nominal routed cable length and assumed aluminium stand density. Do not use the `steel` display key for mass.
5. Keep USD 17,200 and PLN 6,090 separate. Added E05 prices and complete build cost remain unknown. Preserve all operating scenarios and null actual hourly/runtime values.
6. Point links at the bundled file paths. The baseline technical/historical inputs now live under `inputs/C04/inputs/`; E05 inputs under `inputs/E05/main_routes_E05/`.
7. Re-run cost tests and the application's integration, composition and snapshot tests against the exact integrated build. This package alone is not app QA or publication approval.

Minimal review artifacts: `delta_summary.json`, `replacement_map.json`, `material_mass_ledger_E05.json`, `validation.json` and `dependency_manifest.json`.

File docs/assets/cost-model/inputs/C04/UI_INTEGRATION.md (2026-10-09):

# C04 viewer integration contract

The existing `cost-ui.js` data fields and `cost-math.js` formulas remain compatible. Copy this package to the selected viewer's `docs/assets/cost-model` and bump JSON request cache versions. Do not modify historical app data by accident.

Required static copy changes in the corrected viewer:

1. Replace “EUR rim listing includes VAT” with “Priced subset: separate USD and PLN references. PLN tires are gross/brutto; Victron prices are dated 2026 Q2 LATAM USD-C ex VAT. Destination tax and shipping are unresolved.”
2. Remove the RELiON recall warning from the active selection. Keep it only with historical RELiON records. Replace it with current BA02 dry-location, battery restraint/thermal and unimplemented electrical control gates.
3. Replace BFGoodrich/EVO body/wheel labels with Jantsa 10005240, Trelleborg SK-900 12-16.5 12PR and RIMA 22095. Do not present the B14/M16 interface as application-approved.
4. Replace old capacity/count references with two BAT548110620 modules, 10.24 kWh nominal. State that 180 A is a conditional warm-bank development ceiling, not commissioned power capability. Temperature, BMS limits, regen/ATC/ATD and pack-loss stop gates remain unresolved.
5. Change the cost date note to “References reviewed 2026-10-09. Victron values are the dated 2026 Q2 LATAM price list. Listings are not supplier quotations; confirm stock, destination costs and package contents.”
6. Scenario reserve uses USD 4,482 module-only reference and 10.24 kWh nominal capacity. The existing formula will pick these up from JSON; keep user-adjustable assumptions and all actual/complete/runtime outputs null.
7. Show mass as “Known modeled/catalogue subtotal,” not whole-vehicle mass. Preserve unknown entries for drives, tires, nuts, straps/buckles and other omitted purchased components. The accepted subtotal is 1268.0641640992537 kg; linked mass ledgers explain scope and name-based replacement.

Expected default 4 kW scenario: energy USD 0.6666666667/h; labor USD 60/h; module reserve USD 1.09423828125/h; partial subtotal USD 61.760904947916664/h. These are illustrative, incomplete assumptions, not measured or qualified operating results.

The package intentionally does not publish a whole-rover runtime, convert currencies, procure components or label the development model buildable. Supplier images, full web captures, PDFs and restricted manufacturer CAD are absent.

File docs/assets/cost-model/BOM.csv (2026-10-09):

id | name | sku | quantity | quantity_unit | scope | supply_kind | selection_status | essential | unit_price | currency | extended_price | pricing_status | price_source_id | included_in_cost_of | unit_mass_kg | mass_basis | included_in_pinned_mass_subtotal | mass_group | source_ids | notes | quote_date | is_supplier_quote | price_observed_on | price_reference_period | price_source_url | availability | tax_basis | shipping_basis | ledger_node | E05_category | installed_mass_kg | procurement_cut_length_m
frame_R07 | Original welded frame R07 | original:frame_R07 | 1 | each | vehicle | original_fabrication | modeled_original_development | true | null | null | null | unpriced | null | null | 386.9529671773959 | source_snapshot_or_catalogue_not_weighed | true | frame |  | Quote required:stock, welds, post-weld machining, finishing, inspection and scrap. Geometry is not fabrication released. | null | false | null | null | null | null | null | null | null | null | null | null
adapter_R04 | Original tool-flange adapter R04 | original:adapter_R04 | 2 | each | vehicle | original_fabrication | modeled_original_development | true | null | null | null | unpriced | null | null | 1.316846623 | source_snapshot_or_catalogue_not_weighed | true | tools_and_arms |  | Unqualified original adapter; mandatory Robotiq coupling remains separately purchased. Do not add alternative ACC-APL-UR20 plate on top. | null | false | null | null | null | null | null | null | null | null | null | null
arms | Universal Robots UR20 arm | UR20 exact arm-only ordering SKU unresolved | 2 | each | vehicle | purchased_part | baseline_candidate | true | null | null | null | unpriced | null | null | 64 | source_snapshot_or_catalogue_not_weighed | true | tools_and_arms | ur20_quote|ur20_bundles | Purchased-part requirement with unknown price; no evidence of an actual purchase. Exact revision, software, cables, pendant and OEM DC package scope require quote. Controller-inclusive package must replace, not duplicate, the two controller rows. | null | false | null | null | null | null | null | null | null | null | null | null
arm_controllers | Universal Robots OEM DC controller | exact CB revision unresolved | 2 | each | vehicle | purchased_part | baseline_candidate | true | null | null | null | unpriced | null | null | 4.3 | source_snapshot_or_catalogue_not_weighed | true | tools_and_arms | oem_dc_specs|oem_dc_candidate_price|ur20_bundles | Two dimensional reservations.200143 CB5.5 price is shown only as a separate candidate reference because controller revision and package inclusion are unresolved. | null | false | null | null | null | null | null | null | null | null | null | null
grippers | Robotiq 2F-85 basic gripper | AGC-GRP-2F85 | 2 | each | vehicle | purchased_part | baseline_candidate | true | 5205 | USD | 10410.0 | public_reference_not_quote | gripper_price | null | null | unknown | false | tools_and_arms | gripper_price | Manufacturer source ordering text and seller disagree on fingertip inclusion; confirm exact kit. Coupling, cable/interface and any additional fingertips are separately tracked. No gripper mass accepted into pinned subtotal. | null | false | 2026-10-09 | null | https://www.logic-control.com/robotiq-agc-grp-2f85 | contact for lead time; no contact made | not established | not established | null | null | null | null
couplings | Robotiq controller-connected coupling (current CAD reference) | GRP-CPL-062 | 2 | each | vehicle | purchased_part | baseline_candidate | true | 644 | USD | 1288.0 | public_reference_not_quote | coupling_price | null | null | unknown | false | tools_and_arms | coupling_price|coupling_routes|coupling_external_route | Separate purchased electronics-containing coupling; original adapter cannot replace it. GRP-ES-CPL-062 and GRP-ES-CPL-077 are different SKUs. Current visual mesh remains a licensed reference; electrical route and exact cable/interface unresolved. | null | false | 2026-10-09 | null | https://www.kingbarcode.com/GRP-CPL-062 | backorder; price and lead time need supplier confirmation | not established | not established | null | null | null | null
gripper_cable_interface | Gripper device cables, RS485/controller interface and required integration hardware | null | null | each | vehicle | purchased_part | required_unresolved | true | null | null | null | unpriced | null | null | null | unknown | false | tools_and_arms | coupling_external_route|coupling_routes | Two grippers require validated power/communications. Counts and exact cable/USB/interface SKUs remain unknown; do not assume bare coupling price includes full route. | null | false | null | null | null | null | null | null | null | null | null | null
gripper_fingertips | Any additional approved gripper fingertips | null | null | each | vehicle | purchased_part | required_scope_unresolved | true | null | null | null | unpriced | null | null | null | unknown | false | tools_and_arms | gripper_price | Whether separately needed depends on confirmed AGC-GRP-2F85 package contents and task. Do not count included fingertips twice. | null | false | null | null | null | null | null | null | null | null | null | null
structure:rear_right_clamp | rear right clamp | original:rear_right_clamp | 1 | each | vehicle | original_fabrication | development_candidate_not_released | true | null | null | null | unpriced | null | null | 22.23048056057798 | original material-volume estimate; not weighed | true | structure |  | Original CAD material-volume estimate using each source density assumption; includes nominal custom/generic fastener geometry, not measured purchased mass. | null | false | null | null | null | null | null | null | rear_right_clamp | null | null | null
structure:rear_right_upper | rear right upper | original:rear_right_upper | 1 | each | vehicle | original_fabrication | development_candidate_not_released | true | null | null | null | unpriced | null | null | 3.6681890876748207 | original material-volume estimate; not weighed | true | structure |  | Original CAD material-volume estimate using each source density assumption; includes nominal custom/generic fastener geometry, not measured purchased mass. | null | false | null | null | null | null | null | null | rear_right_upper | null | null | null
structure:rear_right_lower | rear right lower | original:rear_right_lower | 1 | each | vehicle | original_fabrication | development_candidate_not_released | true | null | null | null | unpriced | null | null | 10.268957155706405 | original material-volume estimate; not weighed | true | structure |  | Original CAD material-volume estimate using each source density assumption; includes nominal custom/generic fastener geometry, not measured purchased mass. | null | false | null | null | null | null | null | null | rear_right_lower | null | null | null
structure:rear_right_upright | rear right upright | original:rear_right_upright | 1 | each | vehicle | original_fabrication | development_candidate_not_released | true | null | null | null | unpriced | null | null | 9.289272214215286 | original material-volume estimate; not weighed | true | structure |  | Original CAD material-volume estimate using each source density assumption; includes nominal custom/generic fastener geometry, not measured purchased mass. | null | false | null | null | null | null | null | null | rear_right_upright | null | null | null
structure:rear_right_retainer_upper | rear right retainer upper | original:rear_right_retainer_upper | 1 | each | vehicle | original_fabrication | development_candidate_not_released | true | null | null | null | unpriced | null | null | 0.0698968629807323 | original material-volume estimate; not weighed | true | structure |  | Original CAD material-volume estimate using each source density assumption; includes nominal custom/generic fastener geometry, not measured purchased mass. | null | false | null | null | null | null | null | null | rear_right_retainer_upper | null | null | null
structure:rear_right_retainer_lower | rear right retainer lower | original:rear_right_retainer_lower | 1 | each | vehicle | original_fabrication | development_candidate_not_released | true | null | null | null | unpriced | null | null | 0.0698968629807323 | original material-volume estimate; not weighed | true | structure |  | Original CAD material-volume estimate using each source density assumption; includes nominal custom/generic fastener geometry, not measured purchased mass. | null | false | null | null | null | null | null | null | rear_right_retainer_lower | null | null | null
structure:rear_right_inner_tie_pin | rear right inner tie pin | original:rear_right_inner_tie_pin | 1 | each | vehicle | original_fabrication | development_candidate_not_released | true | null | null | null | unpriced | null | null | 0.14257134237654337 | original material-volume estimate; not weighed | true | structure |  | Original CAD material-volume estimate using each source density assumption; includes nominal custom/generic fastener geometry, not measured purchased mass. | null | false | null | null | null | null | null | null | rear_right_inner_tie_pin | null | null | null
structure:rear_right_outer_tie_pin | rear right outer tie pin | original:rear_right_outer_tie_pin | 1 | each | vehicle | original_fabrication | development_candidate_not_released | true | null | null | null | unpriced | null | null | 0.14257134237654365 | original material-volume estimate; not weighed | true | structure |  | Original CAD material-volume estimate using each source density assumption; includes nominal custom/generic fastener geometry, not measured purchased mass. | null | false | null | null | null | null | null | null | rear_right_outer_tie_pin | null | null | null
structure:rear_right_inner_backing_C02_R01 | rear right inner backing C02 R01 | original:rear_right_inner_backing_C02_R01 | 1 | each | vehicle | original_fabrication | development_candidate_not_released | true | null | null | null | unpriced | null | null | 2.3991864732733807 | original material-volume estimate; not weighed | true | structure |  | Original CAD material-volume estimate using each source density assumption; includes nominal custom/generic fastener geometry, not measured purchased mass. | null | false | null | null | null | null | null | null | rear_right_inner_backing_C02_R01 | null | null | null
structure:rear_right_stationary_hardware_C02_R01 | rear right stationary hardware C02 R01 | original:rear_right_stationary_hardware_C02_R01 | 1 | each | vehicle | original_fabrication | development_candidate_not_released | true | null | null | null | unpriced | null | null | 2.061987039990519 | original material-volume estimate; not weighed | true | structure |  | Original CAD material-volume estimate using each source density assumption; includes nominal custom/generic fastener geometry, not measured purchased mass. | null | false | null | null | null | null | null | null | rear_right_stationary_hardware_C02_R01 | null | null | null
structure:rear_right_breakout_bracket_left_C04_R01 | rear right breakout bracket left C04 R01 | original:rear_right_breakout_bracket_left_C04_R01 | 1 | each | vehicle | original_fabrication | development_candidate_not_released | true | null | null | null | unpriced | null | null | 0.08997689119845095 | original material-volume estimate; not weighed | true | structure |  | Original CAD material-volume estimate using each source density assumption; includes nominal custom/generic fastener geometry, not measured purchased mass. | null | false | null | null | null | null | null | null | rear_right_breakout_bracket_left_C04_R01 | null | null | null
structure:rear_right_breakout_standoff_0_C04_R01 | rear right breakout standoff 0 C04 R01 | original:rear_right_breakout_standoff_0_C04_R01 | 1 | each | vehicle | original_fabrication | development_candidate_not_released | true | null | null | null | unpriced | null | null | 0.0029670869991599903 | original material-volume estimate; not weighed | true | structure |  | Original CAD material-volume estimate using each source density assumption; includes nominal custom/generic fastener geometry, not measured purchased mass. | null | false | null | null | null | null | null | null | rear_right_breakout_standoff_0_C04_R01 | null | null | null
structure:rear_right_breakout_standoff_1_C04_R01 | rear right breakout standoff 1 C04 R01 | original:rear_right_breakout_standoff_1_C04_R01 | 1 | each | vehicle | original_fabrication | development_candidate_not_released | true | null | null | null | unpriced | null | null | 0.0029670869991599885 | original material-volume estimate; not weighed | true | structure |  | Original CAD material-volume estimate using each source density assumption; includes nominal custom/generic fastener geometry, not measured purchased mass. | null | false | null | null | null | null | null | null | rear_right_breakout_standoff_1_C04_R01 | null | null | null
structure:rear_right_breakout_carrier_fasteners_C04_R01 | rear right breakout carrier fasteners C04 R01 | original:rear_right_breakout_carrier_fasteners_C04_R01 | 1 | each | vehicle | original_fabrication | development_candidate_not_released | true | null | null | null | unpriced | null | null | 0.016184268990872025 | original material-volume estimate; not weighed | true | structure |  | Original CAD material-volume estimate using each source density assumption; includes nominal custom/generic fastener geometry, not measured purchased mass. | null | false | null | null | null | null | null | null | rear_right_breakout_carrier_fasteners_C04_R01 | null | null | null
structure:rear_left_clamp | rear left clamp | original:rear_left_clamp | 1 | each | vehicle | original_fabrication | development_candidate_not_released | true | null | null | null | unpriced | null | null | 22.23048056057832 | original material-volume estimate; not weighed | true | structure |  | Original CAD material-volume estimate using each source density assumption; includes nominal custom/generic fastener geometry, not measured purchased mass. | null | false | null | null | null | null | null | null | rear_left_clamp | null | null | null
structure:rear_left_upper | rear left upper | original:rear_left_upper | 1 | each | vehicle | original_fabrication | development_candidate_not_released | true | null | null | null | unpriced | null | null | 3.668189087674823 | original material-volume estimate; not weighed | true | structure |  | Original CAD material-volume estimate using each source density assumption; includes nominal custom/generic fastener geometry, not measured purchased mass. | null | false | null | null | null | null | null | null | rear_left_upper | null | null | null
structure:rear_left_lower | rear left lower | original:rear_left_lower | 1 | each | vehicle | original_fabrication | development_candidate_not_released | true | null | null | null | unpriced | null | null | 10.268934620560124 | original material-volume estimate; not weighed | true | structure |  | Original CAD material-volume estimate using each source density assumption; includes nominal custom/generic fastener geometry, not measured purchased mass. | null | false | null | null | null | null | null | null | rear_left_lower | null | null | null
structure:rear_left_upright | rear left upright | original:rear_left_upright | 1 | each | vehicle | original_fabrication | development_candidate_not_released | true | null | null | null | unpriced | null | null | 9.289270852293232 | original material-volume estimate; not weighed | true | structure |  | Original CAD material-volume estimate using each source density assumption; includes nominal custom/generic fastener geometry, not measured purchased mass. | null | false | null | null | null | null | null | null | rear_left_upright | null | null | null
structure:rear_left_retainer_upper | rear left retainer upper | original:rear_left_retainer_upper | 1 | each | vehicle | original_fabrication | development_candidate_not_released | true | null | null | null | unpriced | null | null | 0.06989686298073233 | original material-volume estimate; not weighed | true | structure |  | Original CAD material-volume estimate using each source density assumption; includes nominal custom/generic fastener geometry, not measured purchased mass. | null | false | null | null | null | null | null | null | rear_left_retainer_upper | null | null | null
structure:rear_left_retainer_lower | rear left retainer lower | original:rear_left_retainer_lower | 1 | each | vehicle | original_fabrication | development_candidate_not_released | true | null | null | null | unpriced | null | null | 0.06989686298073232 | original material-volume estimate; not weighed | true | structure |  | Original CAD material-volume estimate using each source density assumption; includes nominal custom/generic fastener geometry, not measured purchased mass. | null | false | null | null | null | null | null | null | rear_left_retainer_lower | null | null | null
structure:rear_left_inner_tie_pin | rear left inner tie pin | original:rear_left_inner_tie_pin | 1 | each | vehicle | original_fabrication | development_candidate_not_released | true | null | null | null | unpriced | null | null | 0.14257134237654343 | original material-volume estimate; not weighed | true | structure |  | Original CAD material-volume estimate using each source density assumption; includes nominal custom/generic fastener geometry, not measured purchased mass. | null | false | null | null | null | null | null | null | rear_left_inner_tie_pin | null | null | null
structure:rear_left_outer_tie_pin | rear left outer tie pin | original:rear_left_outer_tie_pin | 1 | each | vehicle | original_fabrication | development_candidate_not_released | true | null | null | null | unpriced | null | null | 0.14257134237654362 | original material-volume estimate; not weighed | true | structure |  | Original CAD material-volume estimate using each source density assumption; includes nominal custom/generic fastener geometry, not measured purchased mass. | null | false | null | null | null | null | null | null | rear_left_outer_tie_pin | null | null | null
structure:rear_left_inner_backing_C02_R01 | rear left inner backing C02 R01 | original:rear_left_inner_backing_C02_R01 | 1 | each | vehicle | original_fabrication | development_candidate_not_released | true | null | null | null | unpriced | null | null | 2.3991864732733807 | original material-volume estimate; not weighed | true | structure |  | Original CAD material-volume estimate using each source density assumption; includes nominal custom/generic fastener geometry, not measured purchased mass. | null | false | null | null | null | null | null | null | rear_left_inner_backing_C02_R01 | null | null | null
structure:rear_left_stationary_hardware_C02_R01 | rear left stationary hardware C02 R01 | original:rear_left_stationary_hardware_C02_R01 | 1 | each | vehicle | original_fabrication | development_candidate_not_released | true | null | null | null | unpriced | null | null | 2.0619870399905205 | original material-volume estimate; not weighed | true | structure |  | Original CAD material-volume estimate using each source density assumption; includes nominal custom/generic fastener geometry, not measured purchased mass. | null | false | null | null | null | null | null | null | rear_left_stationary_hardware_C02_R01 | null | null | null
structure:rear_left_breakout_bracket_left_C04_R01 | rear left breakout bracket left C04 R01 | original:rear_left_breakout_bracket_left_C04_R01 | 1 | each | vehicle | original_fabrication | development_candidate_not_released | true | null | null | null | unpriced | null | null | 0.08997689119845097 | original material-volume estimate; not weighed | true | structure |  | Original CAD material-volume estimate using each source density assumption; includes nominal custom/generic fastener geometry, not measured purchased mass. | null | false | null | null | null | null | null | null | rear_left_breakout_bracket_left_C04_R01 | null | null | null
structure:rear_left_breakout_standoff_0_C04_R01 | rear left breakout standoff 0 C04 R01 | original:rear_left_breakout_standoff_0_C04_R01 | 1 | each | vehicle | original_fabrication | development_candidate_not_released | true | null | null | null | unpriced | null | null | 0.0029670869991599903 | original material-volume estimate; not weighed | true | structure |  | Original CAD material-volume estimate using each source density assumption; includes nominal custom/generic fastener geometry, not measured purchased mass. | null | false | null | null | null | null | null | null | rear_left_breakout_standoff_0_C04_R01 | null | null | null
structure:rear_left_breakout_standoff_1_C04_R01 | rear left breakout standoff 1 C04 R01 | original:rear_left_breakout_standoff_1_C04_R01 | 1 | each | vehicle | original_fabrication | development_candidate_not_released | true | null | null | null | unpriced | null | null | 0.002967086999159988 | original material-volume estimate; not weighed | true | structure |  | Original CAD material-volume estimate using each source density assumption; includes nominal custom/generic fastener geometry, not measured purchased mass. | null | false | null | null | null | null | null | null | rear_left_breakout_standoff_1_C04_R01 | null | null | null
structure:rear_left_breakout_carrier_fasteners_C04_R01 | rear left breakout carrier fasteners C04 R01 | original:rear_left_breakout_carrier_fasteners_C04_R01 | 1 | each | vehicle | original_fabrication | development_candidate_not_released | true | null | null | null | unpriced | null | null | 0.016184268990872025 | original material-volume estimate; not weighed | true | structure |  | Original CAD material-volume estimate using each source density assumption; includes nominal custom/generic fastener geometry, not measured purchased mass. | null | false | null | null | null | null | null | null | rear_left_breakout_carrier_fasteners_C04_R01 | null | null | null
structure:middle_right_clamp | middle right clamp | original:middle_right_clamp | 1 | each | vehicle | original_fabrication | development_candidate_not_released | true | null | null | null | unpriced | null | null | 19.693450938638954 | original material-volume estimate; not weighed | true | structure |  | Original CAD material-volume estimate using each source density assumption; includes nominal custom/generic fastener geometry, not measured purchased mass. | null | false | null | null | null | null | null | null | middle_right_clamp | null | null | null
structure:middle_right_upper | middle right upper | original:middle_right_upper | 1 | each | vehicle | original_fabrication | development_candidate_not_released | true | null | null | null | unpriced | null | null | 3.2946095768123294 | original material-volume estimate; not weighed | true | structure |  | Original CAD material-volume estimate using each source density assumption; includes nominal custom/generic fastener geometry, not measured purchased mass. | null | false | null | null | null | null | null | null | middle_right_upper | null | null | null
structure:middle_right_lower | middle right lower | original:middle_right_lower | 1 | each | vehicle | original_fabrication | development_candidate_not_released | true | null | null | null | unpriced | null | null | 8.850337690749116 | original material-volume estimate; not weighed | true | structure |  | Original CAD material-volume estimate using each source density assumption; includes nominal custom/generic fastener geometry, not measured purchased mass. | null | false | null | null | null | null | null | null | middle_right_lower | null | null | null
structure:middle_right_upright | middle right upright | original:middle_right_upright | 1 | each | vehicle | original_fabrication | development_candidate_not_released | true | null | null | null | unpriced | null | null | 8.822382493350158 | original material-volume estimate; not weighed | true | structure |  | Original CAD material-volume estimate using each source density assumption; includes nominal custom/generic fastener geometry, not measured purchased mass. | null | false | null | null | null | null | null | null | middle_right_upright | null | null | null
structure:middle_right_outer_pins | middle right outer pins | original:middle_right_outer_pins | 1 | each | vehicle | original_fabrication | development_candidate_not_released | true | null | null | null | unpriced | null | null | 0.7859325076089254 | original material-volume estimate; not weighed | true | structure |  | Original CAD material-volume estimate using each source density assumption; includes nominal custom/generic fastener geometry, not measured purchased mass. | null | false | null | null | null | null | null | null | middle_right_outer_pins | null | null | null
structure:middle_right_inner_backing_C02_R01 | middle right inner backing C02 R01 | original:middle_right_inner_backing_C02_R01 | 1 | each | vehicle | original_fabrication | development_candidate_not_released | true | null | null | null | unpriced | null | null | 2.3991864732733807 | original material-volume estimate; not weighed | true | structure |  | Original CAD material-volume estimate using each source density assumption; includes nominal custom/generic fastener geometry, not measured purchased mass. | null | false | null | null | null | null | null | null | middle_right_inner_backing_C02_R01 | null | null | null
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

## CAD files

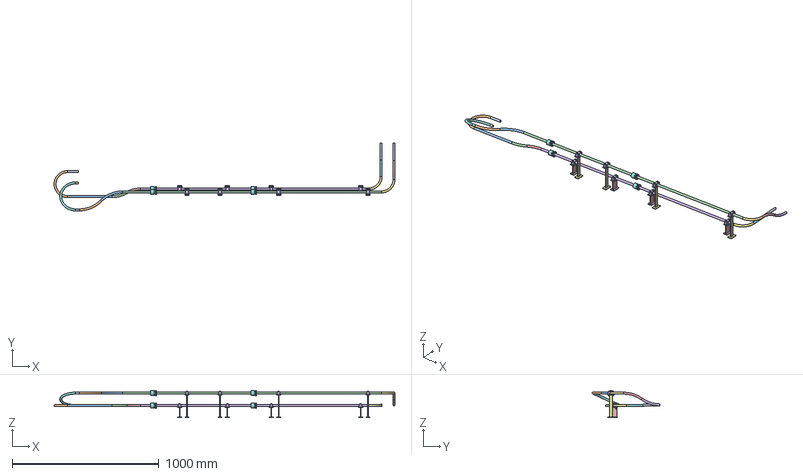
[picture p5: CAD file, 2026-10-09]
docs/assets/cost-model/inputs/E05/main_routes_E05/main_pair_supported_E05.step
2326.3 x 463.1 x 185.7 mm
MAIN_positive_70mm2_routed_jacket
MAIN_positive_support0_M4x30_0
MAIN_positive_support0_upper_washer_0
MAIN_positive_support0_lower_washer_0
MAIN_positive_support0_M4nut_0
MAIN_positive_support0_M4x30_1
MAIN_positive_support0_upper_washer_1
MAIN_positive_support0_lower_washer_1
MAIN_positive_support0_M4nut_1
MAIN_positive_support0_welded_stand
MAIN_positive_support0_lower_clamp
MAIN_positive_support0_upper_clamp
MAIN_positive_support1_M4x30_0
MAIN_positive_support1_upper_washer_0
MAIN_positive_support1_lower_washer_0
MAIN_positive_support1_M4nut_0
MAIN_positive_support1_M4x30_1
MAIN_positive_support1_upper_washer_1
MAIN_positive_support1_lower_washer_1
MAIN_positive_support1_M4nut_1
MAIN_positive_support1_welded_stand
MAIN_positive_support1_lower_clamp
MAIN_positive_support1_upper_clamp
MAIN_positive_support2_M4x30_0
MAIN_positive_support2_upper_washer_0
MAIN_positive_support2_lower_washer_0
MAIN_positive_support2_M4nut_0
MAIN_positive_support2_M4x30_1
MAIN_positive_support2_upper_washer_1
MAIN_positive_support2_lower_washer_1
MAIN_positive_support2_M4nut_1
MAIN_positive_support2_welded_stand
MAIN_positive_support2_lower_clamp
MAIN_positive_support2_upper_clamp
MAIN_positive_support3_M4x30_0
MAIN_positive_support3_upper_washer_0
MAIN_positive_support3_lower_washer_0
MAIN_positive_support3_M4nut_0
MAIN_positive_support3_M4x30_1
MAIN_positive_support3_upper_washer_1
MAIN_positive_support3_lower_washer_1
MAIN_positive_support3_M4nut_1
MAIN_positive_support3_welded_stand
MAIN_positive_support3_lower_clamp
MAIN_positive_support3_upper_clamp
MAIN_negative_70mm2_routed_jacket
MAIN_negative_support0_M4x30_0
MAIN_negative_support0_upper_washer_0
MAIN_negative_support0_lower_washer_0
MAIN_negative_support0_M4nut_0
MAIN_negative_support0_M4x30_1
MAIN_negative_support0_upper_washer_1
MAIN_negative_support0_lower_washer_1
MAIN_negative_support0_M4nut_1
MAIN_negative_support0_welded_stand
MAIN_negative_support0_lower_clamp
MAIN_negative_support0_upper_clamp
MAIN_negative_support1_M4x30_0
MAIN_negative_support1_upper_washer_0
MAIN_negative_support1_lower_washer_0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

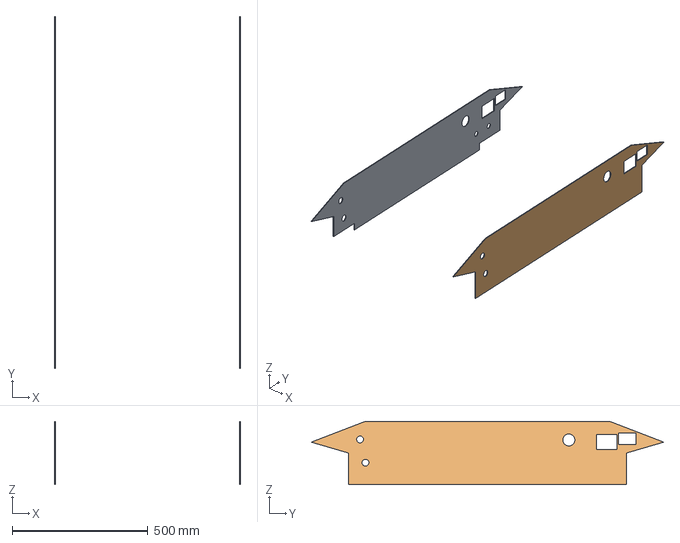
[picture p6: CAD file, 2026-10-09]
docs/assets/cost-model/inputs/E05/main_routes_E05/partition_main_glands_E05.step
686.0 x 1300.0 x 234.0 mm
controller_battery_partition
battery_tool_partition

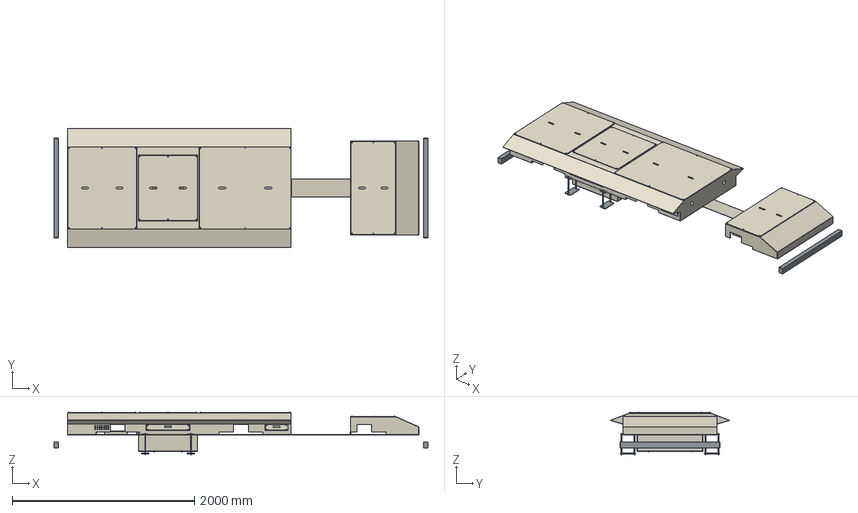
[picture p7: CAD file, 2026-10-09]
docs/assets/body-power/body_power_R01.step
4100.0 x 1301.1 x 466.0 mm
main_base_deck_3mm
main_left_side_3mm
left_side_service_cover_1
left_service_nutclip_1_1
left_service_nutclip_1_2
left_service_nutclip_1_3
left_service_nutclip_1_4
left_side_service_cover_2
left_service_nutclip_2_1
left_service_nutclip_2_2
left_service_nutclip_2_3
left_service_nutclip_2_4
main_right_side_3mm
right_side_service_cover_1
right_service_nutclip_1_1
right_service_nutclip_1_2
right_service_nutclip_1_3
right_service_nutclip_1_4
right_side_service_cover_2
right_service_nutclip_2_1
right_service_nutclip_2_2
right_service_nutclip_2_3
right_service_nutclip_2_4
main_left_lower_sloping_shoulder
main_left_upper_sloping_shoulder
main_right_lower_sloping_shoulder
main_right_upper_sloping_shoulder
rear_bulkhead_3mm
arm_facing_bulkhead_3mm
controller_battery_partition
battery_tool_partition
battery_well_floor_3mm
battery_well_left_wall
battery_well_right_wall
battery_well_rear_wall
battery_well_front_wall
battery_1_isolator_pad
battery_1_stop_-1
battery_1_stop_1
battery_2_isolator_pad
battery_2_stop_-1
battery_2_stop_1
battery_3_isolator_pad
battery_3_stop_-1
battery_3_stop_1
battery_4_isolator_pad
battery_4_stop_-1
battery_4_stop_1
battery_retention_crossbar_1
battery_retention_stud_1_-235
battery_retention_nut_1_-235_bottom
battery_retention_nut_1_-235_top
battery_retention_stud_1_235
battery_retention_nut_1_235_bottom
battery_retention_nut_1_235_top
battery_retention_crossbar_2
battery_retention_stud_2_-235
battery_retention_nut_2_-235_bottom
battery_retention_nut_2_-235_top
battery_retention_stud_2_235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

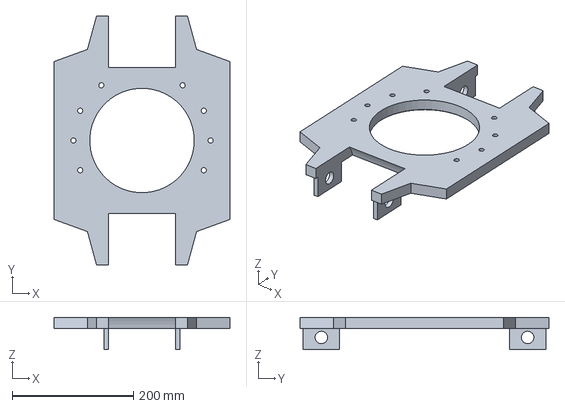
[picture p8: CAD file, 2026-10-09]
docs/assets/corners/upright_WD220_C02_R05.step
290.0 x 410.0 x 53.0 mm

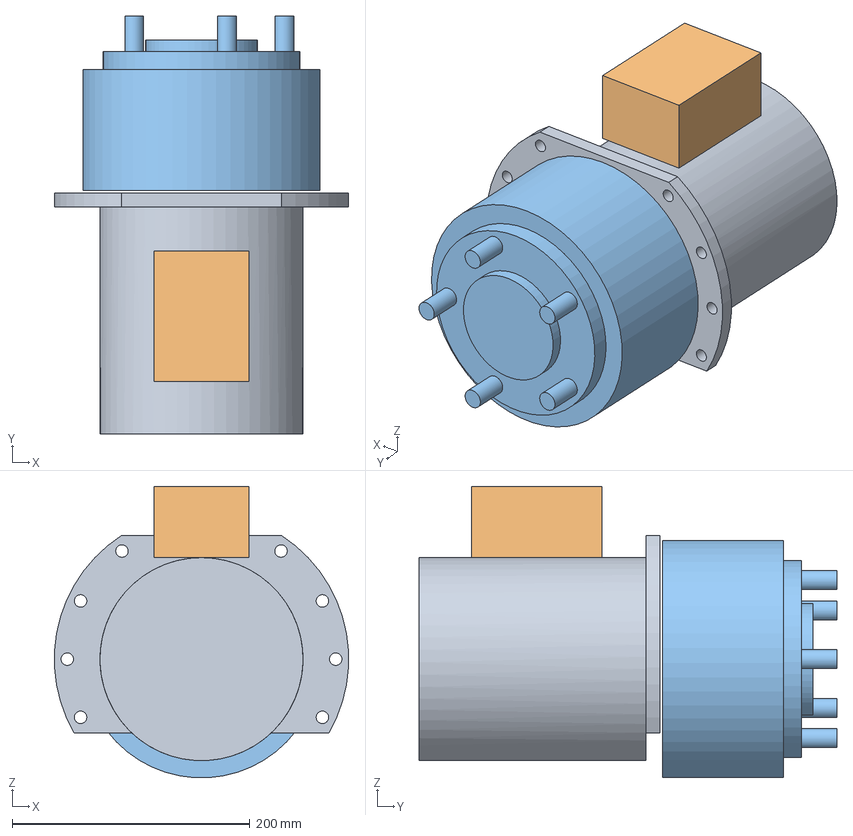
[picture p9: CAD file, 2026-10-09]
docs/assets/integration/drive_envelope_WD220.step
247.6 x 352.0 x 245.3 mm
stator
rotor_with_studs

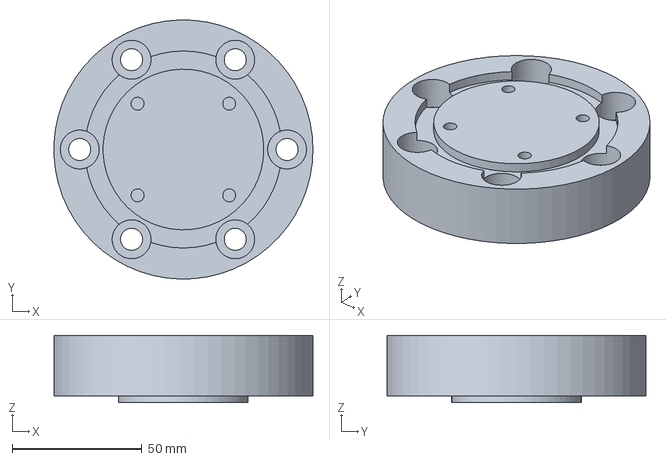
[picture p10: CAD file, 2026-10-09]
docs/assets/mechanical/adapter_R04.step
99.9 x 100.0 x 26.0 mm

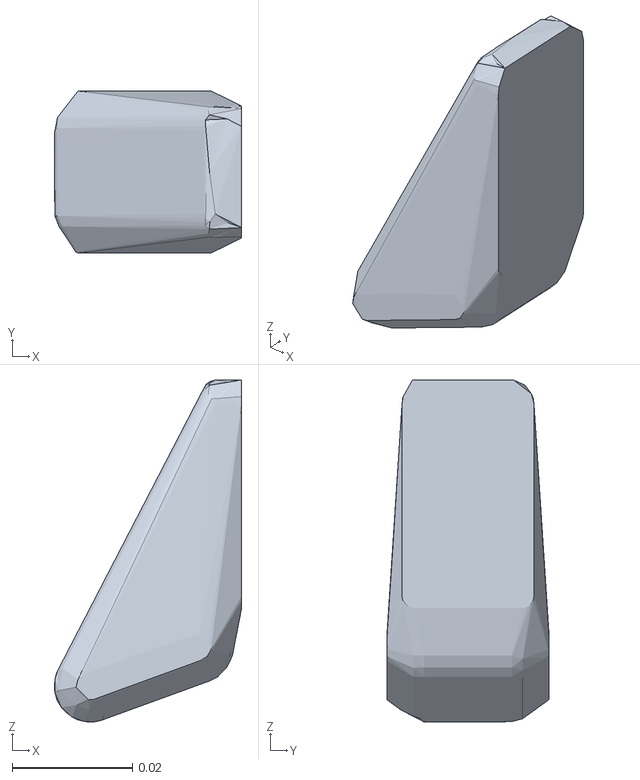
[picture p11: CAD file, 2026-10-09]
docs/assets/robots/source/robotiq/grippers/robotiq_description/meshes/collision/2f_85/right_finger_tip.stl
0.0312 x 0.027 x 0.057

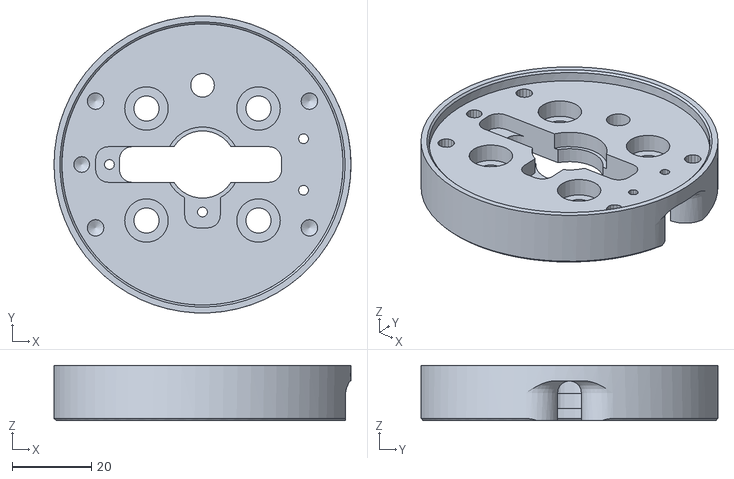
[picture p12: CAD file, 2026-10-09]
docs/assets/robots/source/robotiq/grippers/robotiq_description/meshes/visual/2f_140/robotiq_2f_140_coupling.stl
75.0 x 74.9 x 13.9

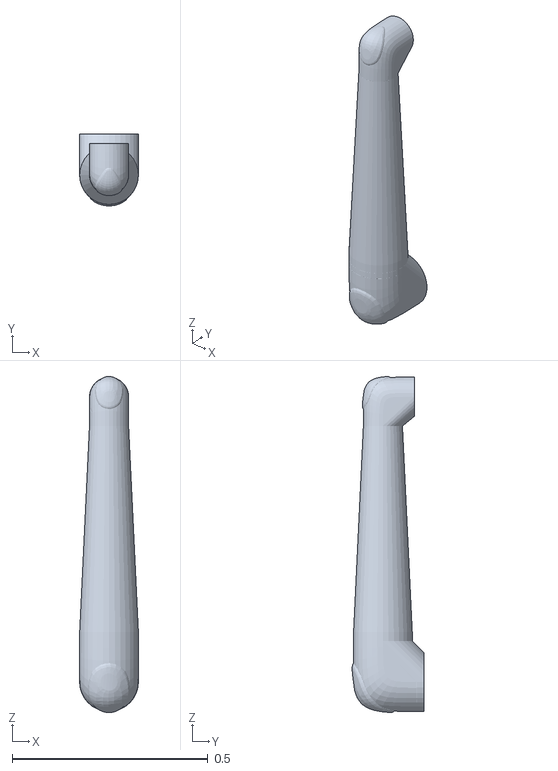
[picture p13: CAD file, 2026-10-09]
docs/assets/robots/source/ur/meshes/ur20/collision/forearm.stl
0.151 x 0.183 x 0.858

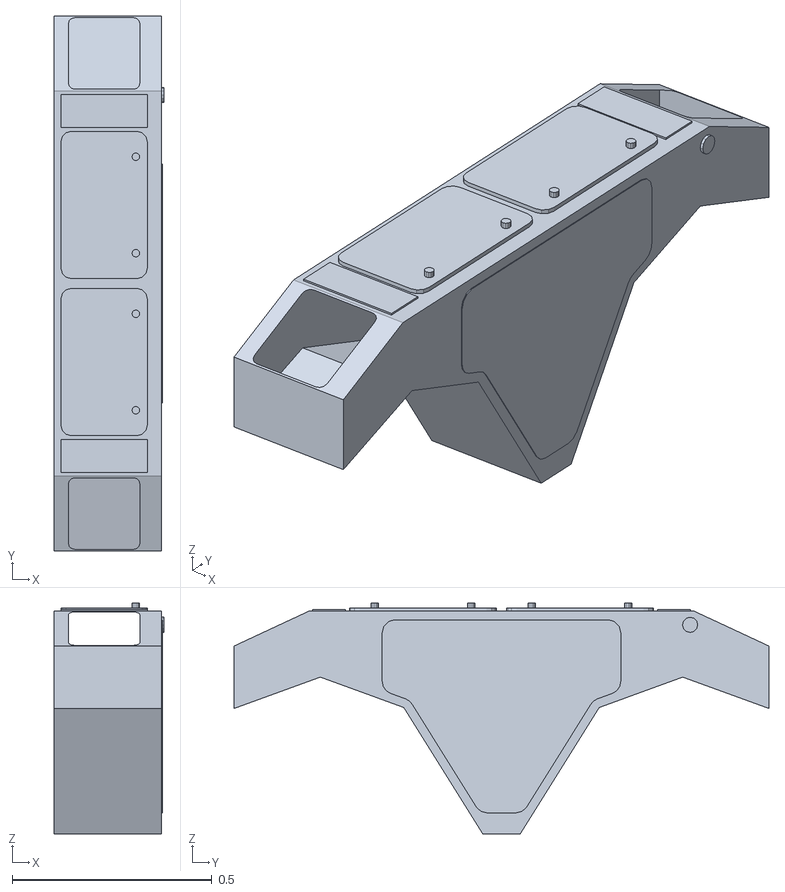
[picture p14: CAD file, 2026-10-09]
docs/assets/running-gear/fenders.stl
0.275 x 1.34 x 0.577

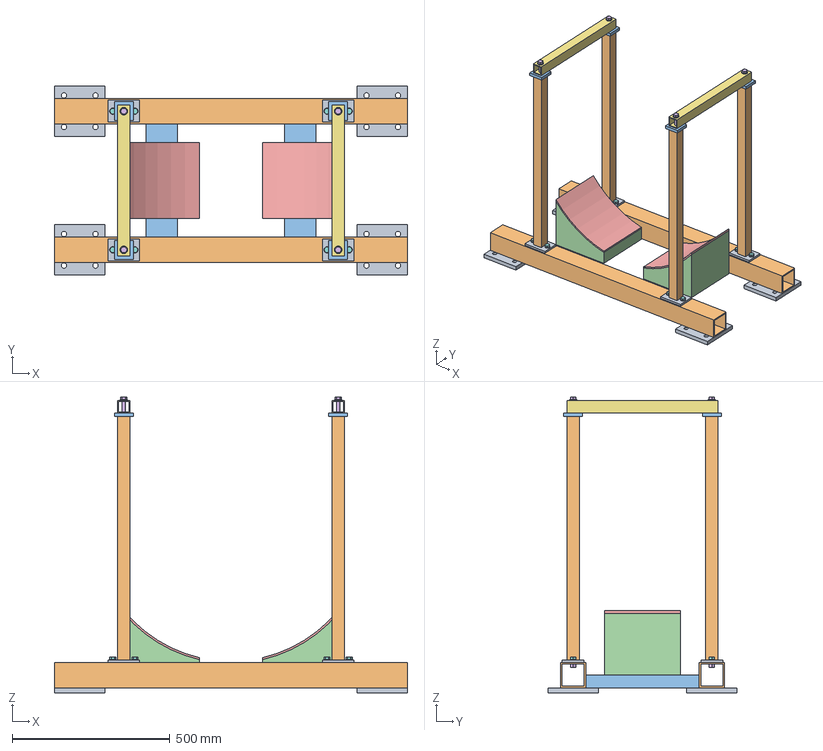
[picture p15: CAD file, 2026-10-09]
docs/assets/service-fixtures/corner_cradle_S01.step
1120.0 x 600.0 x 938.1 mm
cradle_foot_-480_720
cradle_foot_480_720
cradle_longitudinal_box_720
cradle_foot_-480_1160
cradle_foot_480_1160
cradle_longitudinal_box_1160
cradle_cross_box_-220
cradle_contour_shoe_-220
cradle_replaceable_contact_liner_-220
cradle_cross_box_220
cradle_contour_shoe_220
cradle_replaceable_contact_liner_220
cradle_post_base_weldnut_-340_720_-35
cradle_post_base_washer_-340_720_-35
cradle_post_base_bolt_-340_720_-35
cradle_post_base_weldnut_-340_720_35
cradle_post_base_washer_-340_720_35
cradle_post_base_bolt_-340_720_35
cradle_capture_post_base_-340_720
cradle_capture_post_-340_720
cradle_capture_post_cap_-340_720
cradle_capture_weldnut_-340_720
cradle_capture_washer_-340_720
cradle_capture_bolt_-340_720
cradle_post_base_weldnut_-340_1160_-35
cradle_post_base_washer_-340_1160_-35
cradle_post_base_bolt_-340_1160_-35
cradle_post_base_weldnut_-340_1160_35
cradle_post_base_washer_-340_1160_35
cradle_post_base_bolt_-340_1160_35
cradle_capture_post_base_-340_1160
cradle_capture_post_-340_1160
cradle_capture_post_cap_-340_1160
cradle_capture_weldnut_-340_1160
cradle_capture_washer_-340_1160
cradle_capture_bolt_-340_1160
cradle_removable_capture_crossbar_-340
cradle_post_base_weldnut_340_720_-35
cradle_post_base_washer_340_720_-35
cradle_post_base_bolt_340_720_-35
cradle_post_base_weldnut_340_720_35
cradle_post_base_washer_340_720_35
cradle_post_base_bolt_340_720_35
cradle_capture_post_base_340_720
cradle_capture_post_340_720
cradle_capture_post_cap_340_720
cradle_capture_weldnut_340_720
cradle_capture_washer_340_720
cradle_capture_bolt_340_720
cradle_post_base_weldnut_340_1160_-35
cradle_post_base_washer_340_1160_-35
cradle_post_base_bolt_340_1160_-35
cradle_post_base_weldnut_340_1160_35
cradle_post_base_washer_340_1160_35
cradle_post_base_bolt_340_1160_35
cradle_capture_post_base_340_1160
cradle_capture_post_340_1160
cradle_capture_post_cap_340_1160
cradle_capture_weldnut_340_1160
cradle_capture_washer_340_1160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

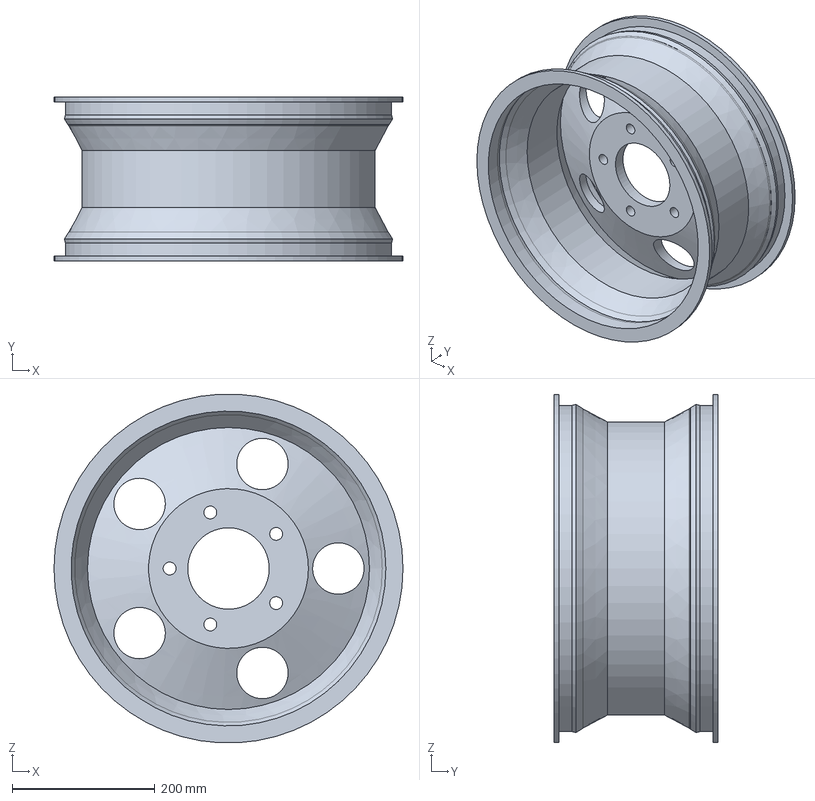
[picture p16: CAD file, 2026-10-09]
docs/assets/wheels/rim_C01.step
489.2 x 229.9 x 488.5 mm

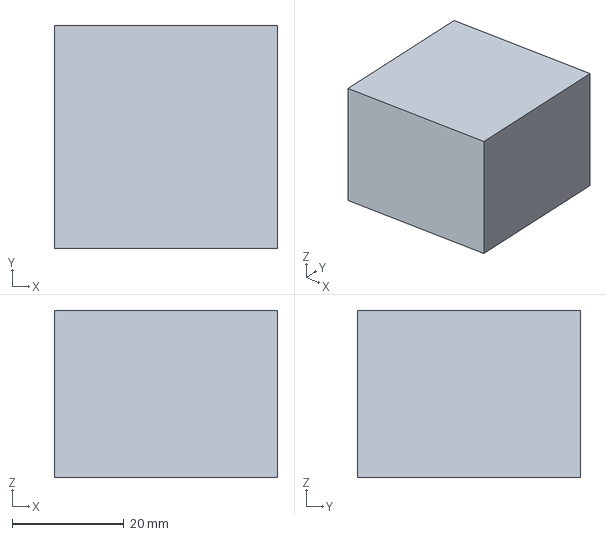
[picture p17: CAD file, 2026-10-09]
docs/contact/assets/coupon_40x40x30_mm.step
40.0 x 40.0 x 30.0 mm

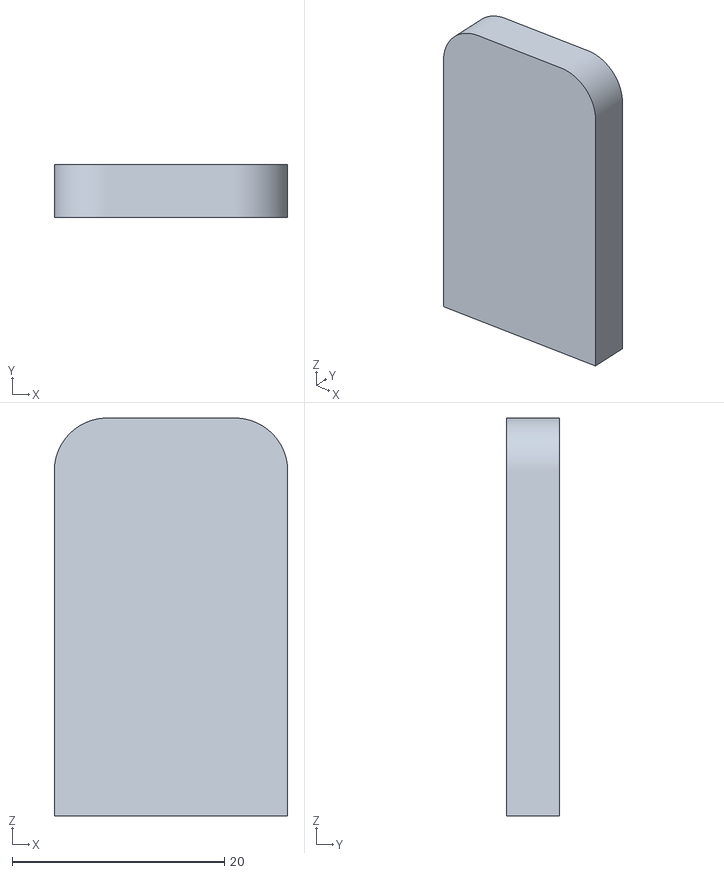
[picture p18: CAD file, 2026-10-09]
docs/contact/assets/robotiq_2f85/assets/pad.stl
22.0 x 5.00 x 37.5

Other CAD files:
docs/assets/body-power/cots_reservations_R01.step
docs/assets/corners/lower_bearing_envelopes_C02_R02.step
docs/assets/integration/coilover_C02.step
docs/assets/mechanical/frame_R07.step
docs/assets/body-power/reference_frame_R06.step
docs/assets/corners/inner_backing_C02_R01.step
docs/assets/corners/lower_wishbone_C02_R02.step
docs/assets/corners/stationary_clamp_C02_R01.step
docs/assets/corners/stationary_hardware_C02_R01.step
docs/assets/corners/upper_bearing_envelopes_C02_R02.step
docs/assets/corners/upper_wishbone_C02_R02.step
docs/assets/corners/upright_WD220_C02_R04.step
docs/assets/corners/upright_pins_C02_R02.step
docs/assets/corners/wheel_adapter_C02_R01.step
docs/assets/corners/wheel_adapter_C02_R02.step
docs/assets/mechanical/adapter_R03.step
docs/assets/robots/source/robotiq/grippers/robotiq_description/meshes/collision/2f_85/left_finger.stl
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

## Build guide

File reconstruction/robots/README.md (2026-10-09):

# Rebuild the OEM robot assets

These instructions work from the repository root in a fresh clone. They require
Python 3.12 or newer with `venv`, a POSIX shell and the files already included in
this repository. No Blender, ROS installation, private CAD files, credentials or
manual source-path edits are needed.

This is a new reconstruction. It does not recover the earlier lost package or
reuse that package's audit result. The retained OEM visual geometry is intended
for visualization and kinematic simulation, not a manufacturing release.

## 1. Prepare a Python environment

Run from the repository root:

```sh
python3 -c "import sys; assert sys.version_info >= (3, 12), 'Python 3.12+ required'"
python3 -m venv .venv-robot-assets
. .venv-robot-assets/bin/activate
python -m pip install -r reconstruction/robots/requirements-build.txt
```

Dependency installation requires access to PyPI. After dependencies are present,
the source-subset build below requires no network access. The original asset
build used NumPy 2.5.3, PyYAML 6.0.3, pycollada 0.9.3 and SciPy 1.17.0.

## 2. Verify the retained source subset

Stay in the repository root. This verifies every retained source file against
the source manifest before it is used:

```sh
python - <<'PY'
import hashlib, json
from pathlib import Path
assets = Path('docs/assets/robots')
manifest = json.loads((assets / 'source-manifest.json').read_text())
for entry in manifest['files']:
    path = assets / entry['path']
    digest = hashlib.sha256(path.read_bytes()).hexdigest()
    if digest != entry['sha256']:
        raise SystemExit(f'Source hash mismatch: {path}')
print(f"Verified {len(manifest['files'])} retained source files")
PY
```

The manifest identifies these source commits:

- UniversalRobots/Universal_Robots_ROS2_Description:
  `6662e15f32c23c12ece57d0050aee9a716e4fc41`
- Robotiq/ros: `adb20dc0048ff2ef51c5a86fe2f7880a8618f099`

A copied source subset is not a Git checkout. File hashes prove agreement with
the retained manifest, while the online method below can independently fetch
the commits from their upstream repositories.

## 3. Build in a fresh temporary directory

The scripts resolve `upstream/`, `dist/` and `conversion-plan.json` relative to
their parent directory. This exact staging procedure provides that layout
without changing the scripts or overwriting the shipped viewer:

```sh
REPO_ROOT="$PWD"
BUILD="$(mktemp -d "${TMPDIR:-/tmp}/six-wheel-robots.XXXXXX")"
export REPO_ROOT BUILD
cp -R reconstruction/robots/scripts "$BUILD/scripts"
cp -R reconstruction/robots/tests "$BUILD/tests"
cp -R docs/assets/robots/source "$BUILD/upstream"
python "$BUILD/scripts/build_metadata.py"
python "$BUILD/scripts/convert_meshes.py"
python "$BUILD/tests/validate_assets.py"
printf 'Rebuilt assets: %s/dist\n' "$BUILD"
```

Expected final test summary: `status: passed`, 17 geometry assets, four arm FK
poses and three gripper FK poses. The largest measured source-vertex difference
in the original reconstruction was approximately `4.42e-8` metres.

The build generates:

- `dist/ur20/`: seven per-link GLB visual meshes
- `dist/robotiq/`: nine gripper-link GLBs and the matching coupling GLB
- `dist/robot-kinematics.json`: source frame graph, limits, mimics and notices
- `dist/fk-fixtures.json`: fresh independently checked transforms
- `dist/geometry-report.json` and `dist/validation-report.json`
- `dist/source/`, `dist/source-manifest.json` and complete `dist/licenses/`

The converter also writes `conversion-plan.json` beside `scripts/` and `tests/`.
No code in these steps publishes files or modifies `docs/`.

## 4. Compare the newly generated GLBs with this release

Keep the same shell, where `BUILD` and `REPO_ROOT` are set:

```sh
python - <<'PY'
import hashlib, json, os
from pathlib import Path
build = Path(os.environ['BUILD']) / 'dist'
shipped = Path(os.environ['REPO_ROOT']) / 'docs/assets/robots'
report = json.loads((build / 'geometry-report.json').read_text())
for entry in report:
    name = entry['asset']
    rebuilt = hashlib.sha256((build / name).read_bytes()).hexdigest()
    released = hashlib.sha256((shipped / name).read_bytes()).hexdigest()
    if rebuilt != released:
        raise SystemExit(f'GLB differs from release: {name}')
print(f'All {len(report)} rebuilt GLBs match the shipped release byte for byte')
PY
```

Validation reports can contain library-version metadata. Compare geometry files
with the command above, and review regenerated reports rather than assuming
that every text file must be byte-identical across different environments.

## Optional: fetch the complete pinned upstream repositories

This is an alternative to copying `docs/assets/robots/source`, not an additional
step inside a source-subset build. Start a separate empty temporary build. It
requires Git and network access to GitHub:

```sh
REPO_ROOT="$PWD"
BUILD="$(mktemp -d "${TMPDIR:-/tmp}/six-wheel-robots-upstream.XXXXXX")"
export REPO_ROOT BUILD
cp -R reconstruction/robots/scripts "$BUILD/scripts"
cp -R reconstruction/robots/tests "$BUILD/tests"
bash "$BUILD/scripts/rebuild.sh"
printf 'Rebuilt assets from upstream commits: %s/dist\n' "$BUILD"
```

The script clones/fetches the two pinned commits, confirms each checked-out
commit, extracts the source subset, converts the meshes and runs the tests.
Do not invoke it in the copied source-subset directory: those folders have no
`.git`, and Git cannot clone over existing source-subset folders.

## Updating the viewer after review

The source-subset build intentionally leaves the existing viewer untouched.
After reviewing a new build, this command copies its generated files into the
viewer asset folder:

```sh
cp -R "$BUILD/dist/." "$REPO_ROOT/docs/assets/robots/"
cd "$REPO_ROOT"
node test-cad.mjs
```

This is only a local file update. Review the diff, run the repository's other
applicable tests, and use its normal authorized commit/deployment process.
Preserve all original source notices and graphical-documentation terms.

## Coordinate and qualification contract

- Units are metres and radians. GLBs retain native right-handed ROS Z-up;
  do not add a Y-up conversion at load time.
- Joint origin order is `T(xyz) * Rz(yaw) * Ry(pitch) * Rx(roll)`, followed by
  joint-axis rotation. Apply `visual.origin` after the link-frame transform.
- `fk-fixtures.json` matrices are row-major 4×4. Three.js `Matrix4.fromArray`
  expects column-major arrays, so transpose/convert when consuming a fixture.
- UR20 has six revolute joints. Robotiq 2F-85 has nine links, six moving joints
  and five mimics. `wrist_3_link → flange → tool0` composes to identity.
- The correct coupling is the source `2f_85/ur_to_robotiq_adapter.dae`, whose
  dedicated URDF specifies zero visual origin and +11 mm to gripper base.
  Its −3 mm outer skirt needs clearance in the custom adapter.
- The project-defined adapter transform and seating remain subject to the
  mechanical interface report. The robot tests do not qualify physical fit,
  tolerances, strength, preload, collisions or robot-specific calibration.
- Source UR20 mass is 64.96 kg, including an explicitly uncertain 4 kg base;
  catalogue 64 kg is retained separately, with no normalization.

Full UR graphical terms and both Robotiq/PickNik BSD notices are retained under
`docs/assets/robots/licenses/`. Original UR texture/logo bytes are embedded in
the GLBs unchanged. Keep the on-screen UR copyright/use notice and the full
terms with the software package. These source meshes confer no blanket
manufacturing license.

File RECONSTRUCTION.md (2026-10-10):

> Historical initial reconstruction record. For the current six-wheel assembly and steering limitations, see [the current assembly record](docs/RECONSTRUCTION.md).

# Six-Wheel Builder: real-CAD reconstruction R01

[Open the viewer](https://rhs059.github.io/drone_test/).

This is a new reconstruction of the previously unpublished local package, not recovery of that package or reuse of its audit results.

- Actual licensed UR20/Robotiq source meshes, original textures and source joint graphs; executable joint/mimic controls.
- Original parametric frame R06 and adapter R03 B-rep/STEP, source generators and fresh checks.
- Standalone MuJoCo native/WASM contact model, with software parity separated from task success. New nominal/heavy cases pass the 10 mm screen; low-friction case fails. These are new declared experiments, not the earlier lost experiments.
- Explicit GPU fallback: CPU kinematics remains usable where WebGPU/WebGL2 is unavailable. Rendered appearance was not independently verified before initial deployment because the QA executor cannot launch Chromium; post-deploy browser checks are separate.

No whole robot, rated drivetrain, collision-free motion, physical manufacturing release, autonomous assembly or repair capability is claimed. A nominal source-frame mating convention is not tolerance/preload/load qualification.

## Reproduce bounded checks

Run `node test-cad.mjs`, `node test-model.mjs` (historical estimates only), and `node docs/contact/scripts/validate.mjs`. Run contact native/WASM generators and mechanical/asset scripts as documented in their folders. Original robot conversion scripts are in `reconstruction/robots/`; retained upstream source/licences and fresh fixtures are in `docs/assets/robots/`. Source paths may need setting to your workspace; the pinned source commits are in the manifest.

## Licensing

Preserve per-asset notices. UR geometry is subject to the complete graphical-documentation terms at `docs/assets/robots/licenses/UR-GRAPHICAL-TERMS.txt`, including displayed copyright and use notice. Robotiq source, MuJoCo Menagerie assets and Three.js carry their respective notices. No blanket license replaces upstream conditions. No private/review-only coupling STEP is included.

## Supported main cable pair

E05 adds exactly 98 named cable/support/retention parts and replaces two partitions for four retained glands. Its graph binds 105 actual scene objects across 22 interface edges. Only the isolator-output to BMS-battery pair has modeled jacket routes; upstream battery wiring, conductor/crimp continuity and full-circuit protection remain unfinished. The 40-hole deck, BA02 parts and corrected terminal polarity are unchanged. The known modeled/catalogue subset is 1272.550107 kg; complete vehicle mass and electrical operation remain unverified. Run `node test-main-pair.mjs` for the actual-GLTFLoader composed regression.

## Inspection visibility

The Outer panels layer hides an explicit set of ten exterior skin pieces plus the 92 removable service-cover/loose-fastener nodes. It retains 185 body nodes, including deck, bulkheads, partitions, battery assemblies, support ledges and nutplates. Electrical hardware and cable supports stay visible. This is an inspection layer, not a removal or load-support procedure. Service-open combines with this layer; Home resets motion without changing either visibility choice. `test-panel-visibility.mjs` checks 18 state transitions and stable component identities.

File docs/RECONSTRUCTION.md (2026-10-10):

# Current connected-component engineering model

This source revision replaces the earlier omitted motors, bearings, rod ends, rack retention and guided spring mounting with inspectable original/source-dimensioned parts. Six direct-drive wheel interfaces use Jantsa 10005240 / Trelleborg SK-900 dimensions. The source manufacturer motor geometry remains private; the public exterior is an original dimensional model.

## Selected geometry and checks

- 126-node structural assembly; continuous mitered hollow arms, restored eight-screw motor mounts, captured rack liners and extended spring supports.
- 816 joint-hardware nodes, six 20-node drive modules, six guided spring modules and direct rim/tire models. Balls and races follow their distinct motion groups.
- Runtime mechanical graph addresses every selected mechanical part; 27 combined motion states are tested. A graph edge records its actual modeled interface and unresolved engineering gates, rather than treating proximity as retention.
- Retained body panels plus selected battery tray and electrical trough changes compose by name into 287 unique parts. Service view removes 92 cover/fastener parts while retained nutplates remain.
- Six controller case interfaces, isolators, BMS, retained carrier hardware and moving breakout boxes are visible. Actual full harness continuity is unfinished; the two UR OEM DC cases have unresolved mounting interfaces.
- STEP-based, sampled private-motor fit results are published only as scoped numeric reports. Restricted manufacturer geometry is excluded.
- The former workshop cradle intersects the revised wheels and lower supports. Its placement control is disabled; failed evidence is preserved.

## Motion and engineering limits

Normal view starts at neutral. Optional unloaded motion studies use q ±12 degrees, independent front/rear rack ±75 mm and wheel spin. The middle pair remains at neutral suspension. The 200 mm raised display is a free-space viewing offset, not a lifting, ground contact or suspension-force result. Sampling does not prove continuous clearance. No physical actuation or vehicle control is connected.

The wheel-seat B14/M16 application, exact supplier profiles, spring rate/preload, guide fits, long-support loads/fatigue, steering force/duty, battery restraint, weather sealing and electrical safety/control integration remain open. Purchased component internal mechanisms are not reverse-engineered. Buildability, driving, peer assembly and autonomous repair are not established.

## Sources and reproduction

[Complete original source packages](assets/connected-sources/index.html), [selected mechanical contract](assets/connected/mechanical-contract.json), [retained interface graph](assets/connected/retained-graph.json), [body composition](assets/connected-body/body-contract.json), [electrical scope](assets/connected-electrical/electrical-contract.json), [numeric audit whitelist](assets/connected-audit/whitelist.json), and [matched cost/BOM](assets/cost-model/cost_model.json).

Run the repository's selected connected-mechanics, composed-body, electrical-scene, rigid-matrix, readiness, costs and UR source-kinematics tests. Historical C03 tests/assets remain as revision history and do not qualify this revision. The standalone MuJoCo contact experiment remains a separate fixed-base task.

## Cost and mass

The known modeled/catalogue subtotal is partial; complete vehicle mass and center of gravity remain unknown. USD and PLN price references are kept separate. Battery reserve calculations use two 5.12 kWh modules and the dated module-price reference. All hourly values are explicit adjustable scenarios, not measured operating costs or runtime claims.

## Battery terminal correction

[Verified polarity and source proof](assets/battery-polarity/README.md) supersedes the frozen BA02 assumed terminal names. Installed +Y is positive and −Y negative. Runtime labels and isolated colors use this mapping; immutable source aliases are retained for traceability. Geometry and hardware qualification are unchanged.

## Supported main cable pair

E05 adds exactly 98 named cable/support/retention parts and replaces two partitions for four retained glands. Its graph binds 105 actual scene objects across 22 interface edges. Only the isolator-output to BMS-battery pair has modeled jacket routes; upstream battery wiring, conductor/crimp continuity and full-circuit protection remain unfinished. The 40-hole deck, BA02 parts and corrected terminal polarity are unchanged. The known modeled/catalogue subset is 1272.550107 kg; complete vehicle mass and electrical operation remain unverified. Run `node test-main-pair.mjs` for the actual-GLTFLoader composed regression.

## Inspection visibility

The Outer panels layer hides an explicit set of ten exterior skin pieces plus the 92 removable service-cover/loose-fastener nodes. It retains 185 body nodes, including deck, bulkheads, partitions, battery assemblies, support ledges and nutplates. Electrical hardware and cable supports stay visible. This is an inspection layer, not a removal or load-support procedure. Service-open combines with this layer; Home resets motion without changing either visibility choice. `test-panel-visibility.mjs` checks 18 state transitions and stable component identities.

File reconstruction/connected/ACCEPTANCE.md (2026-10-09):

# Connected drivetrain release acceptance

This revision must replace absent hardware with source-backed parts and explicit interfaces, rather than infer connections from kinematic motion.

## Mechanical evidence required

For each of six corners, identify the ordered torque/load path: wheel rim, correctly seated wheel fasteners, direct wheel pilot, motor output flange/studs (no adapter in the selected C04 direct-drive candidate), motor bearings/housing and fixed mounting flange/fasteners, upright, spherical or pivot joints, wishbones, chassis pivots/clamps and frame. For four steering corners also identify rack actuator mount, actuator eye and pin, rod/carriage connection, rack guides, inner rod-end ball/spacers/pin, threaded tie tube/insert/jam nuts, outer rod-end and upright lever. Include spring/damper eye hardware and attachments at both ends.

Each interface record must have component IDs, source-backed mating datum/axis, rendered node names, local mating anchor transforms, joint type and permitted movement, exact source or original drawing, retention method and unresolved tolerances. A merely coincident center is insufficient to establish a retained joint. Distinguish physical purchased component models from original designs and dimensional assumptions.

Across the displayed motion domain, verify actual rendered transforms of all connected hardware: bearing ball vs housing, rod-end bodies vs tie rods, spacer/pin axes, actuator endpoint/length closure, shock endpoints and wheel/motor/coaxial flange transforms. Record sampled angular misalignment, engagement/retention limits and tested geometry. Do not substitute snapshot arithmetic for actual scene-matrix checks.

## Electrical evidence required

Every powered component must trace to a source through actual compatible drive/control hardware and protected conductors, including return paths. Identify each motor's winding/type, feedback and brake interface; selected controller compatibility; battery configuration/BMS; branch protection, isolation, contactors and precharge; regeneration handling; arm power input; steering power/control; auxiliary supply; communications and emergency-stop architecture. Unknown supplier interfaces remain explicit blockers, not invented terminals.

Use manufacturer ratings with their duty, temperature, phase-vs-bus-current and configuration conditions. Provide source-backed enclosure/mounting/connector geometry and conductor endpoint data. Visual cables must terminate on named terminals/connectors and follow moving parts with documented bend/slack allowances. Routing appearance does not establish cable ampacity, fault interruption, EMC, thermal performance or functional safety.

## Visual QA

Close views with body visible and removed must show all six wheel-to-drive paths and every steering/suspension connection. Highlight by component identity, never obscure omissions with wireframe reservations. Inspect neutral and combined motion extrema. Missing purchased profiles may use accurately dimensioned original interface models only when the modeled dimensions and assumptions are explicit; do not derive public geometry from restricted vendor CAD.

## Completion boundary

A model with attached solids and continuity tests is a connected engineering design, not a fabrication release. Do not call it buildable while specific mounting, hardware stack, controller compatibility, load support or electrical protection requirements remain unresolved. Preserve prior failed configurations and qualification limits.

Current viewer motion scope: front/rear four-corner suspension and independent racks. The middle pair remains fixed at neutral; wheel-spin binding can be studied on all six. This does not establish middle suspension travel clearance.

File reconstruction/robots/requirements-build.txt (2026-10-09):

numpy==2.5.3
PyYAML==6.0.3
pycollada==0.9.3
scipy==1.17.0

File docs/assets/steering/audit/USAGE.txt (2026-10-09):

Extract C03_sources_tests.zip and C03_assembly_glb.zip into the same directory.
The resulting folder must contain mechanical/running_gear_C03/ with the contract,
solver, manifest, original GLB and README. Install NumPy and SciPy, and have Node.js
available on PATH.

From that extracted directory, default relative paths:
  python /path/to/audit_c03.py
  python /path/to/audit_glb.py

Or, from any directory, explicit locations:
  python /path/to/audit_c03.py --source-root /path/to/extracted/mechanical/running_gear_C03 --output-dir /path/to/fresh-output
  python /path/to/audit_glb.py --source-root /path/to/extracted/mechanical/running_gear_C03 --output-dir /path/to/fresh-output

Run audit_c03.py first. Both default to a fresh ./steering-audit-output location,
rather than overwriting the supplied audit evidence directory. Choose a separate
output directory when preserving a previous run. Existing files in the selected
output directory are replaced by a rerun. Both scripts exit nonzero on audit failure;
missing source/fixture paths produce a clear usage error before executing the audit.

The original evidence and timestamps were preserved. Both full reproduction runs
match the original fixtures byte for byte, GLB evidence exactly, and FK summary
except its new generation timestamp. See portability_receipt.json for script hashes.

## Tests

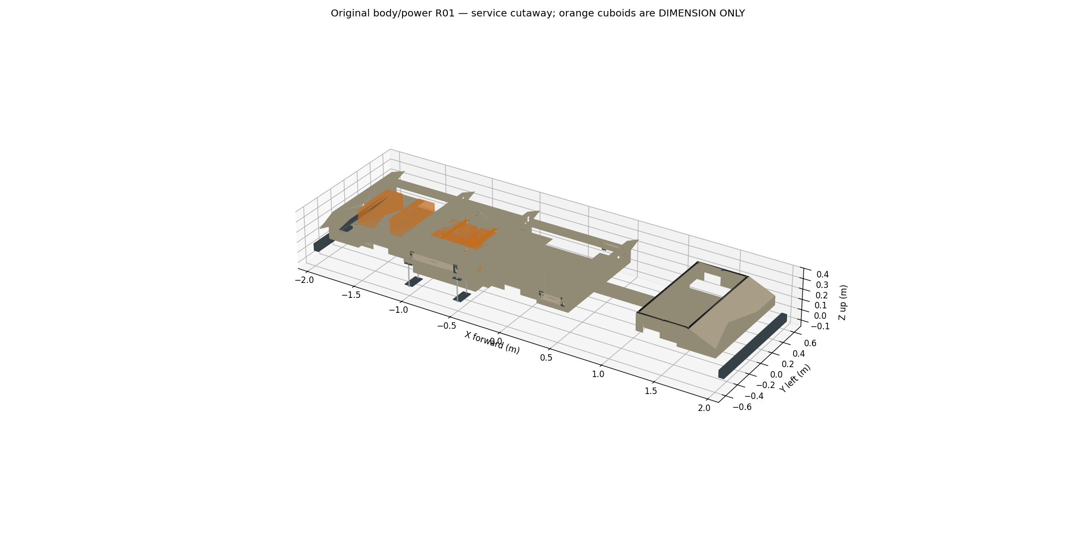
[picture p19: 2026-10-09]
docs/assets/body-power/body_cutaway_qa.png

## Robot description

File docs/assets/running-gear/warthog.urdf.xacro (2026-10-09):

<?xml version='1.0'?>

<robot name="warthog" xmlns:xacro="http://www.ros.org/wiki/xacro">

  <xacro:property name="PI" value="3.1415926535897931"/>

  <xacro:property name="wheel_radius" value="0.3" />
  <xacro:property name="wheel_width" value="0.25" />
  <xacro:property name="wheel_mass" value="15" />
  <xacro:property name="wheel_to_track_ratio" value="0.5962" />

  <xacro:property name="axle_x_offset" value="0.457367" />
  <xacro:property name="axle_y_offset" value="0.0" />
  <xacro:property name="axle_z_offset" value="-0.012977" />

  <xacro:property name="diff_unit_length" value="1.34" />
  <xacro:property name="diff_unit_width" value="0.28" />
  <xacro:property name="diff_unit_height" value="0.63"/>
  <xacro:property name="diff_unit_mass" value="50" />

  <xacro:property name="diff_unit_offset_x" value="0.00" />
  <xacro:property name="diff_unit_offset_y" value="0.56821" />
  <xacro:property name="diff_unit_offset_z" value="0.0" />

  <xacro:property name="chassis_length" value="1.35" />
  <xacro:property name="chassis_width" value="0.70" />
  <xacro:property name="chassis_height" value="0.30" />
  <xacro:property name="chassis_mass" value="100" />

  <xacro:property name="dummy_inertia" value="1e-09"/>

  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
  <xacro:property name="warthog_color" value="$(optenv WARTHOG_COLOR yellow)" />
  <xacro:if value="${warthog_color == 'yellow'}">
    <xacro:property name="warthog_color_rgba" value="0.95 0.816 0.082 1.0" />
  </xacro:if>
  <xacro:if value="${warthog_color == 'orange'}">
    <xacro:property name="warthog_color_rgba" value="1.0 0.48 0.0 1.0" />
  </xacro:if>
  <xacro:if value="${warthog_color == 'olive'}">
    <xacro:property name="warthog_color_rgba" value="0.333 0.419 0.184 1.0" />
  </xacro:if>
  <xacro:if value="${warthog_color == 'sand'}">
    <xacro:property name="warthog_color_rgba" value="0.86 0.75 0.54 1.0" />
  </xacro:if>

  <xacro:macro name="wheel_inertia" params="m r h">
    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
  </xacro:macro>

  <xacro:macro name="box_inertia" params="m x y z">
    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
  </xacro:macro>

  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

  <xacro:macro name="wheel" params="prefix side *joint_pose">
    <link name="${prefix}_${side}_wheel_link">
      <inertial>
        <origin xyz="0 0 0" rpy="0 0 0" />
        <mass value="${wheel_mass}" />
        <xacro:wheel_inertia m="${wheel_mass}" r="${wheel_radius}" h="${wheel_width}" />
      </inertial>
      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
    </link>
    <joint name="${prefix}_${side}_wheel_joint" type="continuous">
      <parent link="${side}_diff_unit_link"/>
      <child link="${prefix}_${side}_wheel_link"/>
      <xacro:insert_block name="joint_pose" />
      <axis xyz="0 1 0"/>
    </joint>
    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
  </xacro:macro>

  <xacro:macro name="track" params="prefix side *joint_pose">
    <link name="${prefix}_${side}_track_link">
      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
    </link>
    <joint name="${prefix}_${side}_track_joint" type="fixed">
      <parent link="${side}_diff_unit_link"/>
      <child link="${prefix}_${side}_track_link"/>
      <xacro:insert_block name="joint_pose" />
      <axis xyz="0 1 0"/>
    </joint>

    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
    <link name="${prefix}_${side}_wheel_link">
      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
    </link>
    <joint name="${prefix}_${side}_wheel_joint" type="continuous">
      <parent link="${side}_diff_unit_link"/>
      <child link="${prefix}_${side}_wheel_link"/>
      <xacro:insert_block name="joint_pose" />
      <axis xyz="0 1 0"/>
    </joint>
    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
  </xacro:macro>

  <xacro:unless value="$(optenv WARTHOG_TRACKS 0)">
    <xacro:wheel prefix="front" side="left">
      <origin xyz="${axle_x_offset*1} ${axle_y_offset*1} ${axle_z_offset}" rpy="0 0 0" />
    </xacro:wheel>
    <xacro:wheel prefix="front" side="right">
      <origin xyz="${axle_x_offset*1} ${axle_y_offset*-1} ${axle_z_offset}" rpy="0 0 0" />
    </xacro:wheel>
    <xacro:wheel prefix="rear" side="left">
      <origin xyz="${axle_x_offset*-1} ${axle_y_offset*1} ${axle_z_offset}" rpy="0 0 0" />
    </xacro:wheel>
    <xacro:wheel prefix="rear" side="right">
      <origin xyz="${axle_x_offset*-1} ${axle_y_offset*-1} ${axle_z_offset}" rpy="0 0 0" />
    </xacro:wheel>
  </xacro:unless>

  <xacro:if value="$(optenv WARTHOG_TRACKS 0)">
    <xacro:track prefix="front" side="left">
      <origin xyz="${axle_x_offset*1} ${axle_y_offset*1} ${axle_z_offset}" rpy="0 0 0" />
    </xacro:track>
    <xacro:track prefix="front" side="right">
      <origin xyz="${axle_x_offset*1} ${axle_y_offset*-1} ${axle_z_offset}" rpy="0 0 0" />
    </xacro:track>
    <xacro:track prefix="rear" side="left">
      <origin xyz="${axle_x_offset*-1} ${axle_y_offset*1} ${axle_z_offset}" rpy="0 0 ${PI}" />
    </xacro:track>
    <xacro:track prefix="rear" side="right">
      <origin xyz="${axle_x_offset*-1} ${axle_y_offset*-1} ${axle_z_offset}" rpy="0 0 ${PI}" />
    </xacro:track>
  </xacro:if>

  <xacro:macro name="diff_unit" params="prefix side left">
    <link name="${prefix}_diff_unit_link">
      <inertial>
        <origin xyz="0 ${side*-1*0.05} 0.197" rpy="0 0 0"/>
        <mass value="${diff_unit_mass}"/>
        <xacro:box_inertia m="${diff_unit_mass}" x="${diff_unit_length}" y="${diff_unit_width}" z="${diff_unit_height}" />
      </inertial>
      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
    </link>
    <joint name="${prefix}_diff_unit_joint" type="revolute">
      <limit upper="0.4" lower="-0.4" effort="100" velocity="1"/>
      <parent link="chassis_link"/>
      <child link="${prefix}_diff_unit_link"/>
      <origin xyz="${diff_unit_offset_x} ${diff_unit_offset_y*side} ${diff_unit_offset_z}" rpy="0 0 0" />
      <axis xyz="0 1 0"/>
      <dynamics damping="100" friction="0.5"/>
    </joint>

    <link name="${prefix}_diff_unit_buttons_link">
      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
    </link>
    <joint name="${prefix}_diff_unit_buttons" type="fixed">
      <origin xyz="0 0 0" rpy="0 0 ${side*PI/2}"/>
      <parent link="${prefix}_diff_unit_link"/>
      <child link="${prefix}_diff_unit_buttons_link"/>
    </joint>

    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
    <link name="${prefix}_diff_unit_antenna_link">
      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
    </link>
    <joint name="${prefix}_diff_unit_antenna_joint" type="fixed">
      <origin xyz="0 0 0" rpy="0 0 ${side*PI/2}"/>
      <parent link="${prefix}_diff_unit_link" />
      <child link="${prefix}_diff_unit_antenna_link" />
    </joint>

    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
    <xacro:if value="${side == -1}">
      <link name="${prefix}_diff_unit_estop_antenna_link">
        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
      </link>
      <joint name="${prefix}_diff_unit_estop_antenna_joint" type="fixed">
        <origin xyz="0 0 0" rpy="0 0 ${side*PI/2}"/>
        <parent link="${prefix}_diff_unit_link"/>
        <child link="${prefix}_diff_unit_estop_antenna_link"/>
      </joint>
    </xacro:if>

    <link name="${prefix}_diff_unit_headlight_link">
      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
    </link>
    <joint name="${prefix}_diff_unit_headlight_joint" type="fixed">
      <parent link="${prefix}_diff_unit_link" />
      <child link="${prefix}_diff_unit_headlight_link" />
      <origin xyz="0 0 0" rpy="0 0 0"/>
    </joint>
    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

    <link name="${prefix}_diff_unit_taillight_link">
      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
    </link>
    <joint name="${prefix}_diff_unit_taillight_joint" type="fixed">
      <parent link="${prefix}_diff_unit_link" />
      <child link="${prefix}_diff_unit_taillight_link" />
      <origin xyz="0 0 0" rpy="0 0 0"/>
    </joint>
    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
  </xacro:macro>

  <xacro:diff_unit prefix="left" side="1" left="true"/>
  <xacro:diff_unit prefix="right" side="-1" left="false"/>

  <link name="base_link"></link>

  <joint name="base_link_joint" type="fixed">
    <origin xyz="0 0 0.025" rpy="0 0 0" />
    <parent link="base_link"/>
    <child link="chassis_link" />
  </joint>

  <link name="chassis_link">
    <inertial>
      <origin xyz="0 0 0" rpy="0 0 0"/>
      <mass value="${chassis_mass}"/>
      <xacro:box_inertia m="${chassis_mass}" x="${chassis_length}" y="${chassis_width}" z="${chassis_height}" />
    </inertial>
    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
  </link>

  <link name="top_chassis_link"></link>

  <joint name="top_link_joint" type="fixed">
    <origin xyz="0 0 0.27218" rpy="0 0 0" />
    <parent link="chassis_link"/>
    <child link="top_chassis_link" />
  </joint>
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

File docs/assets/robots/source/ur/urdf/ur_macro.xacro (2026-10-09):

<?xml version="1.0"?>
<robot xmlns:xacro="http://wiki.ros.org/xacro">
  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

  <xacro:include filename="$(find ur_description)/urdf/inc/ur_common.xacro" />

  <xacro:macro name="ur_robot" params=" name tf_prefix parent *origin joint_limits_parameters_file kinematics_parameters_file physical_parameters_file visual_parameters_file safety_limits:=false safety_pos_margin:=0.15 safety_k_position:=20 force_abs_paths:=false ">

    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
    <xacro:read_model_data joint_limits_parameters_file="${joint_limits_parameters_file}" kinematics_parameters_file="${kinematics_parameters_file}" physical_parameters_file="${physical_parameters_file}" visual_parameters_file="${visual_parameters_file}" force_abs_paths="${force_abs_paths}"/>

    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
    <link name="${tf_prefix}base_link"/>
    <link name="${tf_prefix}base_link_inertia">
      <xacro:get_visual_params name="base" type="mesh_offset"/>
      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
      <xacro:cylinder_inertial radius="${base_inertia_radius}" length="${base_inertia_length}" mass="${base_mass}">
        <origin xyz="0 0 0" rpy="0 0 0" />
      </xacro:cylinder_inertial>
    </link>
    <link name="${tf_prefix}shoulder_link">
      <xacro:get_visual_params name="shoulder" type="mesh_offset"/>
      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
      <inertial>
        <mass value="${shoulder_mass}"/>
        <origin rpy="${shoulder_inertia_rotation}" xyz="${shoulder_cog}"/>
        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
      </inertial>    </link>
    <link name="${tf_prefix}upper_arm_link">
      <xacro:get_visual_params name="upper_arm" type="mesh_offset"/>
      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
      <inertial>
        <mass value="${upper_arm_mass}"/>
        <origin rpy="${upper_arm_inertia_rotation}" xyz="${upper_arm_cog}"/>
        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
      </inertial>
    </link>
    <link name="${tf_prefix}forearm_link">
      <xacro:get_visual_params name="forearm" type="mesh_offset"/>
      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
      <inertial>
        <mass value="${forearm_mass}"/>
        <origin rpy="${forearm_inertia_rotation}" xyz="${forearm_cog}"/>
        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
      </inertial>
    </link>
    <link name="${tf_prefix}wrist_1_link">
      <xacro:get_visual_params name="wrist_1" type="mesh_offset"/>
      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
      <inertial>
        <mass value="${wrist_1_mass}"/>
        <origin rpy="${wrist_1_inertia_rotation}" xyz="${wrist_1_cog}"/>
        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
      </inertial>
    </link>
    <link name="${tf_prefix}wrist_2_link">
      <xacro:get_visual_params name="wrist_2" type="mesh_offset"/>
      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
      <inertial>
        <mass value="${wrist_2_mass}"/>
        <origin rpy="${wrist_2_inertia_rotation}" xyz="${wrist_2_cog}"/>
        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
      </inertial>
    </link>
    <link name="${tf_prefix}wrist_3_link">
      <xacro:get_visual_params name="wrist_3" type="mesh_offset"/>
      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
      <inertial>
        <mass value="${wrist_3_mass}"/>
        <origin rpy="${wrist_3_inertia_rotation}" xyz="${wrist_3_cog}"/>
        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
      </inertial>
    </link>

    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
    <joint name="${tf_prefix}base_joint" type="fixed">
      <xacro:insert_block name="origin" />
      <parent link="${parent}" />
      <child link="${tf_prefix}base_link" />
    </joint>
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

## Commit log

2026-10-09 Add Six-Wheel Builder baseline 01 and Pages-ready engineering workbench
2026-10-09 Deploy tested Six-Wheel Builder docs from main to GitHub Pages
2026-10-09 Document fresh CAD reconstruction after unrecovered local package
2026-10-09 Checkpoint reconstructed CAD viewer code; asset verification pending
2026-10-09 Publish reconstructed real CAD, source kinematics and standalone contact experiments
    [adapter_R03.step, base.stl, base_mount.stl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]
2026-10-09 Preserve pinned licensed running-gear references for original six-wheel design
    [diff-link.stl, fenders.stl, rocker.stl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]
2026-10-09 Add buildability (DFM) screen for STEP parts and R06/R03 results
    dfm_check.py flags non-standard stock (EN 10029 plate, EN 10219 RHS),
    hole sizes outside ISO tap-drill/ISO 273 clearance tables, counterbores
    not matching DIN 974-1 for the screw, and drilled holes whose drill exit
    or fastener access is blocked by another part. test_dfm.py is a
    known-answer test covering each defect class.
    R06: 4 UR20 deck pilots land on crossmember_04/05 walls.
    R03: M8 counterbores are Ø14, DIN 974-1 gives Ø15 for ISO 4762.
    Claude-Session: https://claude.ai/code/session_01SBQYCKjeY1ft4t7KSuPx4W
2026-10-09 Checkpoint original rover body and source-backed wheel CAD with fresh geometry evidence
    [body_power_R01.step, cots_reservations_R01.step, original_cutlist.csv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]
2026-10-09 Integrate six source-backed wheel assemblies, faceted body and service access for pre-release visual audit
    [adapter_R04.step, frame_R07.step, frame_R07_cutlist.csv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]
2026-10-09 Run assembled-rover checks in CI and preserve unknown bearing masses on regeneration
2026-10-09 Correct fine-thread wheel adapter pilots and freeze audited six-wheel development snapshot
    [wheel_adapter_C02_R02.step]
2026-10-09 Restore sourced build and operating costs and add original workshop support study
    [BOM.csv, chassis_trestles_S01.step, corner_cradle_S01.step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]
2026-10-09 Clarify fixture-only pin clearance and unresolved wheel-nut mass
    [BOM.csv]
2026-10-09 Gate model controls until CAD is ready and restore state safely
2026-10-09 Add source-backed front/rear steering geometry study and matched C03 mass/BOM
    [BOM.csv]
2026-10-09 Document sampled motor-fit pass and combined-travel failures; make audits portable
    [motor-fit-neutral-sampled.json, motor-fit-travel-failures.json]
2026-10-09 Integrate clearance-revised CAD arms and bounded unloaded suspension motion study
    [BOM.csv, motor-placement-numeric-contract.json, private-C03-nominal-motor-wheel-fit.json]
2026-10-09 Add assembly connectivity check, WD220 drive envelope, coilover sweep and integration handoff
    - assembly_check.py: touch graph from frame over STEP parts placed as rover.js
    places them; declared internal joints; --corner fast mode
    - integration/drive_envelope_WD220: public-dimension hub-drive solid that
    mates upright face Y797 to adapter face Y928; corner now 58/58 connected
    - integration/coilover_C02: envelope, +-12 deg clash sweep, motion ratio and
    spring rates; finds the contract coilover line passes through the drive
    - integration/HANDOFF.md: specs and pass/fail tests for coilover relocation,
    48 V harness, viewer, body fasteners, protrusion regression, tire drone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
    [coilover_C02.step, drive_envelope_WD220.step]
2026-10-09 Connect six-wheel CAD hardware and electrical component assemblies with retained interfaces and scoped evidence
    [BOM.csv, battery_original_hardware_mass.csv, private_motor_R08_X_bound_numeric_check.json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]
2026-10-09 Restore exact CAD source node names after GLTFLoader parsing; regress actual loader body assembly
2026-10-09 Add retained main cable pair, matched partition glands and reproducible cost ledger
    [BOM.csv, battery_original_hardware_mass.csv, main_pair_supported_E05.step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]
2026-10-09 Keep battery, deck and cable supports visible when hiding outer inspection panels
2026-10-09 Add C04 suspension behaviour review and script
    Runs the viewer's kinematics_C04_R03 module: wheel travel/track change,
    motion ratio, steer range, tyre-to-spring clearance and spring force vs
    vehicle mass. Findings: spring sized for 1.6-2.0 t only (coil bind at the
    3.94 t case), 9.4 N/mm wheel rate on 109 mm travel, 380 mm cantilevered
    lower shock mount, 0.57 mm/mm scrub, 186 mm kingpin offset with no KPI.
    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
2026-10-09 Add live-scene corner contact check and drive/wheel-removal/brake review
    corner_contact_dump.js samples surface points from the running viewer;
    corner_contact_gaps.py measures all 28 declared joints of the front-left
    chain (all touching, <=1.6 mm). Review adds drive speed, steering layout,
    wheel-removal path and parking-brake capacity vs vehicle mass and slope;
    no service brake exists.
    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
